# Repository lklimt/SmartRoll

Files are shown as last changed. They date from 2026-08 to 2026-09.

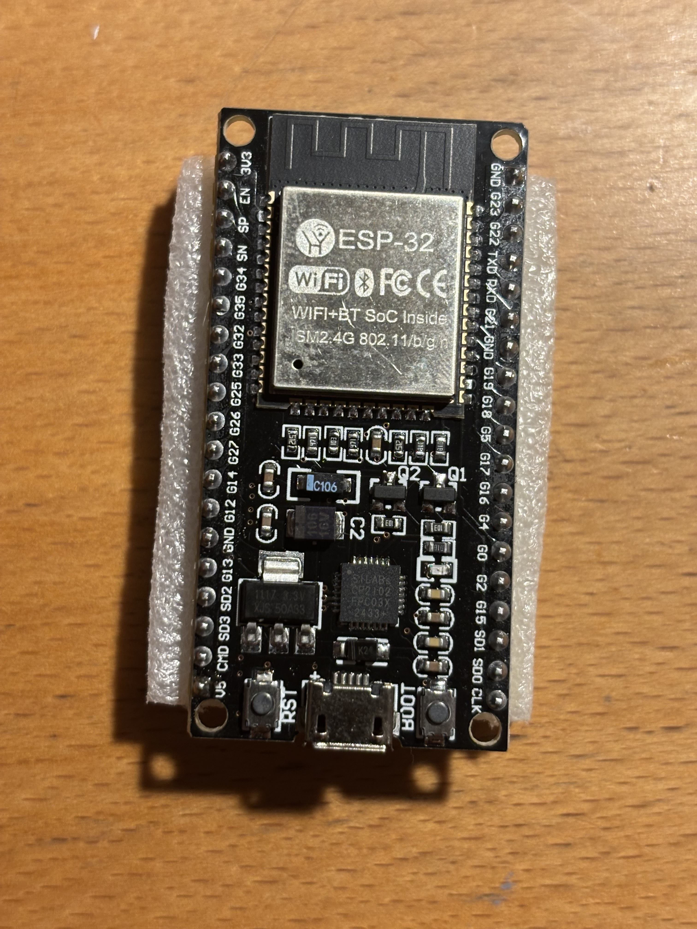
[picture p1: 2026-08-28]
images/components/ESP32-DevKit-38pin.jpeg

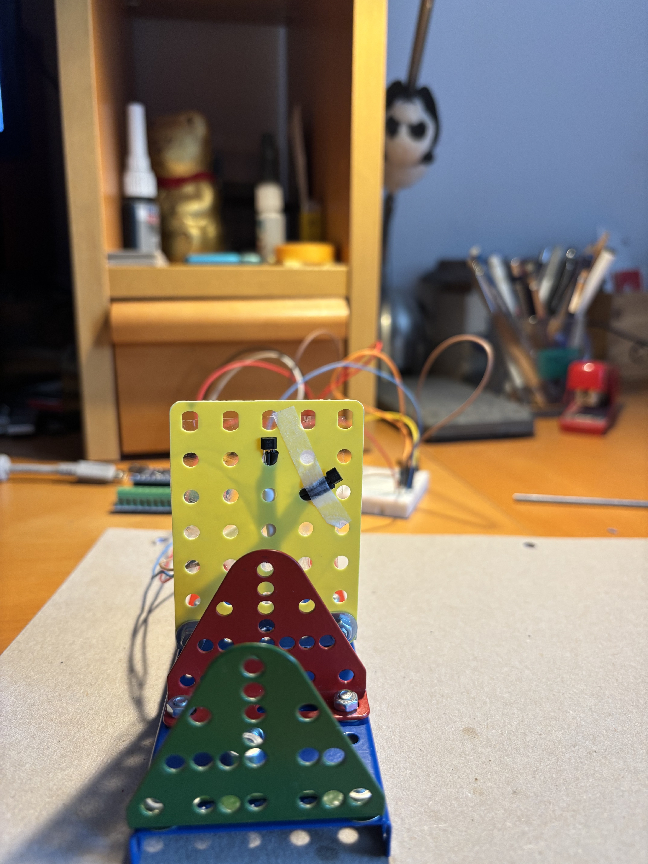
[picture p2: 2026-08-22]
tests/hall_sensor_test/evidence/hall-45stupnu.jpeg

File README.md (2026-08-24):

# SmartRoll

Automated control system for external roller blinds with **ERTE ET 45E tubular motors**.

SmartRoll combines the previously developed ControlRoll RF control with Hall-based direction/position sensing and additional environmental sensors in **one Wemos D1 mini / ESP8266 controller**.

## Project documentation

- [Technical Specification](SPECIFICATION.md)
- [System Architecture and D1 feasibility](docs/09_system_architecture.md)
- [Mechanical Design](docs/02_mechanical_design.md)
- [Hall Sensor Specification](docs/03_hall_sensor.md)
- [Electronics](docs/04_electronics.md)
- [Change Log](CHANGELOG.md)

## Target single-ESP architecture

One Wemos D1 mini / ESP8266 is planned to handle:

- Hall A + Hall B quadrature direction sensing
- relative roller position counting
- 433 MHz RF UP / STOP / DOWN control
- motion sensor
- temperature sensor
- light sensor
- Wi-Fi / Home Assistant communication

The Arduino Nano remains a **development/test platform only**.

## Initial GPIO allocation

| Function | Wemos pin | ESP GPIO |
|---|---|---:|
| Hall A | D1 | GPIO5 |
| Hall B | D2 | GPIO4 |
| Motion | D5 | GPIO14 |
| Temperature | D6 | GPIO12 |
| RF transmitter | D7 | GPIO13 |
| Light | A0 | ADC |

D3/GPIO0, D4/GPIO2 and D8/GPIO15 are reserved because they are ESP8266 boot-sensitive pins.

## Approved Hall arrangement

```text
2 magnets, 180° apart
Hall A + Hall B directly beside each other
5 mm successful test air gap

CW : 11 → 10 → 00 → 01 → 11
CCW: 11 → 01 → 00 → 10 → 11
```

The quadrature decoder and restart direction recovery have been experimentally validated on the Arduino Nano test fixture.

## Relationship to ControlRoll

The previous [ControlRoll](https://github.com/lklimt/ControlRoll) project used a Wemos D1 together with a separate Arduino Nano for RF transmission. SmartRoll is the next architecture: RF generation is moved into the ESP8266 so the production controller does not require the Arduino Nano.

The existing ControlRoll RF protocol and roller command codes are retained as the reference for the RF migration and must be verified before production firmware release.

## Repository structure

```text
SmartRoll/
├── README.md
├── SPECIFICATION.md
├── CHANGELOG.md
├── docs/
│   ├── 01_project_overview.md
│   ├── 02_mechanical_design.md
│   ├── 03_hall_sensor.md
│   ├── 04_electronics.md
│   ├── 05_firmware.md
│   ├── 06_home_assistant.md
│   ├── 07_testing.md
│   ├── 08_manufacturing.md
│   └── 09_system_architecture.md
├── mechanical/
│   ├── freecad/
│   │   ├── macros/
│   │   ├── models/
│   │   └── references/
│   ├── stl/
│   └── drawings/
├── electronics/
│   ├── schematics/
│   └── pcb/
├── firmware/
├── measurements/
├── tests/
└── images/
```

The technical specification is the source of truth for approved project parameters. Experimental results are retained as evidence but do not override the approved specification.

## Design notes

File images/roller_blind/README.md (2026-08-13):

# Roller Blind – General Photos

Photographs documenting the complete external roller-blind installation and its mechanical surroundings.

Use this directory for:
- overall installation views,
- motor-side views,
- wall/cassette relationship,
- available clearance,
- general orientation references.

File naming convention:
`NN_description.ext`

Example: `01_overall_motor_side.jpg`

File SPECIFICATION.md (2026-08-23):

# SmartRoll – Technical Specification

**Project:** SmartRoll  
**Repository:** `lklimt/SmartRoll`  
**Status:** Work in Progress  
**Current mechanical revision:** SR-MEC-001 Rev.F

## 1. Purpose

SmartRoll is an automated control system project for **external roller blinds equipped with ERTE ET 45E tubular motors**.

The project includes the mechanical carrier, magnetic sensing, electronics, firmware, Home Assistant integration, testing and manufacturing documentation.

This document is the technical source of truth for the project.

## 2. Specification Rules

- **CONFIRMED** – directly measured or explicitly confirmed.
- **DECIDED** – explicitly approved design decision.
- **ASSUMED** – temporary assumption; not a final manufacturing dimension.
- **OPEN** – information still requiring measurement or decision.
- **SUPERSEDED** – previous value/design replaced by a newer result.

Unknown dimensions shall be marked `OPEN`, never invented.

FreeCAD macros are implementation tools, not the source of design requirements. A macro must derive fixed dimensions and geometry from this specification and must not silently introduce final values for `OPEN` parameters.

Every substantial mechanical change receives a new revision. Historical revisions remain historical.

# 3. Mechanical System

## 3.1 Roller-blind application

- Application: **external roller blinds**.
- Motor: **ERTE ET 45E tubular motor**.

**Status: CONFIRMED**

## 3.2 Roller-blind shaft

The roller blind uses an octagonal shaft.

| Parameter | Value | Status |
|---|---:|---|
| Shaft type | Octagonal | CONFIRMED |
| Across flats | 16.70 mm | CONFIRMED |
| Surface containing slat feature | 5 + 6.7 + 5 mm | CONFIRMED |
| Carrier clamping zone width | 6 mm | DECIDED |

The 16.70 mm value is the relevant distance across opposing flats. The face containing the slat feature is the primary mechanical reference.

The exact global CAD coordinate convention remains **OPEN** and shall be fixed before the production macro is finalized.

## 3.3 Available space

| Condition | Available space | Status |
|---|---:|---|
| Blind unrolled | approx. 35 mm from wall | CONFIRMED |
| Blind wound | approx. 30 mm effective space | CONFIRMED |

The approximately 30 mm wound condition is the limiting clearance condition unless a later measurement establishes a smaller value.

## 3.4 Stationary and rotating areas

The right-hand side contains a stationary black mounting part including the motor programming button. The rotating part begins approximately **24 mm from the right-hand side**.

The magnetic carrier must not:

- contact the stationary mounting part,
- obstruct the programming button,
- prevent operation or programming of the ERTE ET 45E motor,
- enter the stationary portion of the mechanism.

**Status: CONFIRMED / APPROXIMATE where noted; DECIDED as design constraint.**

# 4. Magnetic Carrier – SR-MEC-001

The carrier is a **two-piece component** clamped around the octagonal shaft. The two halves are installed independently and mechanically joined.

The carrier consists of two functional zones:

1. **Shaft clamping zone** – positively locked to the octagonal shaft.
2. **Magnetic rotating zone** – carries the magnets and provides circular clearance around the stationary mechanism.

The two zones must not be confused: the shaft-clamping geometry follows the octagonal shaft, while the magnetic section uses circular rotating clearance.

**Status: DECIDED**

## 4.1 Shaft clamping

- Octagonal internal geometry matching the shaft.
- Shaft AF: **16.70 mm**.
- Clamping section width: **6 mm**.
- Rotation shall be transmitted positively and shall not rely on friction alone.
- Slat clearance shall be provided on the correct shaft face.

## 4.2 Slat clearance

The slat clearance is rotated **90° relative to the carrier split / M3 joining arrangement**.

The clearance shall be large enough for the actual shaft feature while removing as little carrier material as practical.

Exact depth and detailed shape remain **OPEN** until measured geometry is entered.

## 4.3 M3 clamping

The two carrier halves use **two M3 connections**.

Requirements:

- closed screw bosses,
- accessible M3 screw heads,
- M3 nut pockets with anti-rotation retention,
- hardware outside the rotating clearance,
- sufficient material around the bosses.

The two halves shall clamp the shaft securely without obstructing the magnetic rotation.

# 5. Approved Magnet Arrangement

| Parameter | Value | Status |
|---|---:|---|
| Number of magnets | 2 | DECIDED |
| Angular separation | 180° | DECIDED |
| Magnet orientation | Radial | DECIDED |
| Magnet polarization | Same in tested arrangement | CONFIRMED |
| Nominal magnet size | 4 × 2 mm | DECIDED |

The magnets are positioned opposite each other and inserted radially from the outside of the carrier into secure pockets.

The final pocket depth and exact retention method remain **OPEN** until production verification.

# 6. Approved Hall Sensor Arrangement

The approved Hall arrangement is:

- **2 Hall sensors**, Hall A and Hall B,
- Hall A and Hall B mounted **directly beside each other**,
- no intentional large angular separation between Hall A and Hall B,
- nominal tested air gap: **5 mm**.

This close A/B arrangement is essential to the verified quadrature signal and avoids an unwanted magnetic dead zone between the sensors.

A **10 mm** air gap was experimentally found unreliable. **5 mm** was reliable, including rapid manual rotation faster than the expected roller-blind motor speed.

**Status: APPROVED TEST CONFIGURATION.**

The exact production Hall mounting dimensions and final air gap remain subject to mechanical verification.

# 7. Approved Hall Quadrature Signal

With Hall A and Hall B directly beside each other, the experimentally verified state sequences are:

### Clockwise rotation – CW

```text
11 → 10 → 00 → 01 → 11
```

### Counter-clockwise rotation – CCW

```text
11 → 01 → 00 → 10 → 11
```

All four states occur:

```text
00
01
10
11
```

The two physical directions therefore produce opposite state ordering and can be distinguished unambiguously.

# 8. Approved Direction Decoder

SmartRoll shall use a **2-bit quadrature state-transition decoder** based on the complete previous-state → new-state transition.

## 8.1 CW transitions

```text
11 → 10
10 → 00
00 → 01
01 → 11
```

Each is one valid CW movement increment.

## 8.2 CCW transitions

```text
11 → 01
01 → 00
00 → 10
10 → 11
```

Each is one valid CCW movement increment.

## 8.3 Invalid transitions

Any transition not listed above is **INVALID**.

An invalid transition shall:

- increment a diagnostic invalid-transition counter,
- not count as normal movement,
- not by itself reverse the detected direction.

The decoder must not determine direction from either Hall signal individually.

## 8.4 Physical direction vs blind movement

`CW` and `CCW` describe physical rotation only.

The final system shall map physical direction to:

- **WIND** – movement toward the rolled-up position.
- **UNWIND** – movement toward the extended position.

This mapping shall be configurable during installation/calibration and shall not be hard-coded from assumed sensor orientation.

# 9. Restart and Power-Failure Behavior

The controller must reacquire direction after restart or power failure without requiring the previous direction to survive in RAM.

Startup procedure:

1. Read the current Hall A/B state.
2. Store it as `previousState`.
3. Set direction to `UNKNOWN`.
4. Wait for the next Hall state change.
5. Decode the valid transition.
6. Set direction to CW or CCW.
7. Continue relative movement counting.

Example:

```text
Restart
  ↓
Read A/B = 11
  ↓
Direction = UNKNOWN
  ↓
11 → 10
  ↓
Direction = CW
```

The opposite valid transition similarly establishes CCW.

The controller shall not infer direction from the motor command alone and shall not assume that the blind is stationary at startup.

**Status: DECIDED and experimentally verified on Arduino Nano.**

# 10. Absolute Position After Power Failure

Exact absolute blind position recovery immediately after a power failure is **not required**.

The ERTE ET 45E motor has programmed upper and lower travel limits. Hall sensing is therefore used for relative rotation and movement counting.

A power failure during movement may temporarily leave the software position offset from the physical position. This is acceptable.

After complete travel to a known upper or lower motor endpoint, SmartRoll shall resynchronize its software position to that known endpoint.

No additional absolute-position sensor is required for this recovery concept.

**Status: DECIDED.**

# 11. Relative Position Counting – OPEN

Valid quadrature transitions provide signed relative movement counts.

The system shall distinguish between:

- raw Hall state changes,
- valid quadrature transitions,
- signed shaft rotation count,
- calibrated blind position.

The following values still require measurement and shall not be guessed:

- valid transitions per shaft revolution,
- shaft revolutions per full blind travel,
- conversion between Hall count and blind position.

# 12. Verification Completed

The approved Hall concept has been experimentally verified on the Merkur-based development fixture using an Arduino Nano.

Completed tests:

1. Two magnets 180° apart.
2. Hall A/B sensors directly beside each other.
3. CW and CCW state-sequence verification.
4. Five rotations CW and five rotations CCW.
5. Direction changes during operation.
6. Rapid manual rotation faster than expected roller-blind motor speed.
7. 5 mm air-gap reliability test – reliable.
8. 10 mm air-gap test – unreliable.
9. Reset while operating CW.
10. Reset while operating CCW.
11. Correct direction reacquisition after reset.
12. No invalid transitions in the recorded normal-operation tests.

The quadrature direction algorithm is therefore **experimentally validated on the Arduino Nano test platform**.

Evidence is stored in:

```text
/tests/hall_sensor_test/evidence/
```

Detailed measurement history is stored in:

```text
/tests/hall_sensor_test/measurement_log.md
```

# 13. Test Platform vs Production Platform

The Arduino Nano / ATmega328P is **test hardware only**.

The final SmartRoll control unit will use an **ESP microcontroller**.

Therefore:

- Arduino pin assignments are not production assignments.
- Arduino-specific timing/interrupt implementation is not a production requirement.
- The validated quadrature transition behavior is the functional requirement.
- Final ESP firmware shall implement equivalent behavior using ESP-compatible GPIO handling.

# 14. Production Electrical Parameters – OPEN

The following require final component selection and verification:

- Hall sensor part number,
- final ESP model,
- ESP GPIO assignments,
- Hall supply voltage,
- Hall output type/polarity,
- pull-up arrangement,
- input protection,
- filtering/debounce if required,
- maximum expected transition frequency.

# 15. Mechanical Verification Requirements

Before a carrier revision is considered production-ready, verify:

1. correct 16.70 mm shaft engagement,
2. correct slat clearance,
3. correct orientation of the carrier halves,
4. secure M3 clamping,
5. accessible M3 screw heads,
6. correct nut retention,
7. secure magnet retention,
8. magnets remain 180° apart,
9. Hall A/B remain directly beside each other,
10. production air gap is within the validated magnetic operating range,
11. no intrusion into circular rotating clearance,
12. no interference with the stationary mounting part,
13. programming button remains accessible,
14. sufficient clearance in the approximately 30 mm wound condition,
15. secure torque transmission from shaft to carrier.

A CAD model alone does not constitute mechanical verification.

# 16. Parameters That Must NOT Be Guessed

The following shall remain `OPEN` unless explicitly measured or decided:

- exact stationary-holder diameter,
- exact distance between stationary holder and wall,
- exact programming-button geometry,
- exact slat-feature geometry,
- exact depth and width of slat clearance,
- final carrier outer diameter,
- final magnetic-section dimensions,
- final magnet-pocket geometry,
- final M3 boss dimensions,
- final printing tolerances,
- final material and print orientation,
- final Hall mounting dimensions,
- final production air gap,
- position calibration constants.

# 17. FreeCAD Macro Requirements

Production macros shall:

- contain clearly named parameters,
- separate confirmed/decided dimensions from `OPEN` dimensions,
- generate both carrier halves,
- preserve the 16.70 mm octagonal shaft geometry,
- preserve the 6 mm clamping-zone width,
- include the slat clearance in the correct orientation,
- provide circular rotating clearance in the magnetic section,
- place two radial magnet pockets 180° apart,
- preserve the approved Hall A/B installation geometry,
- provide two functional M3 joining bosses,
- provide complete M3 screw-head seats,
- provide anti-rotation nut pockets,
- keep M3 hardware outside the rotating clearance,
- keep the programming button accessible,
- expose `OPEN` dimensions at the top of the macro,
- never silently replace confirmed dimensions with approximations.

# 18. Superseded Hall Experiments

Previous experiments using Hall sensors separated by approximately **30°, 45° or 90°** are now **SUPERSEDED**.

They are retained only as historical evidence. They shall **not** be used as:

- production mechanical references,
- firmware references,
- direction-algorithm references,
- geometry references for the final Hall installation.

In particular, the former 30° arrangement and its associated state machine are obsolete.

The approved reference is exclusively:

```text
2 magnets, 180° apart
Hall A + Hall B directly beside each other
5 mm successful test air gap

CW : 11 → 10 → 00 → 01 → 11
CCW: 11 → 01 → 00 → 10 → 11
```

# 19. Current Approved Hall Status

### APPROVED

- external roller blinds with ERTE ET 45E motors,
- 2 magnets,
- magnets 180° apart,
- same magnet polarization in tested arrangement,
- radial magnet orientation,
- 2 Hall sensors,
- Hall A/B directly beside each other,
- successful 5 mm test air gap,
- 2-bit quadrature decoding,
- complete-state transition direction detection,
- invalid-transition handling,
- restart direction reacquisition,
- relative movement counting concept,
- no requirement for exact absolute position immediately after power failure,
- endpoint resynchronization using motor limits,
- Arduino Nano as test platform,
- ESP as final controller platform.

### OPEN

- final Hall sensor selection,
- final ESP model and GPIO assignment,
- production Hall mounting dimensions,
- production air gap,
- electrical interface details,
- transitions per revolution calibration,
- blind-position calibration,
- final mechanical carrier verification.

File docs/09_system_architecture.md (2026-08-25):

# SmartRoll – System Architecture

**Status:** APPROVED ARCHITECTURE BASELINE / implementation OPEN

## 1. Objective

SmartRoll combines the functions previously developed in the separate `ControlRoll` project with the new SmartRoll sensing and position functions.

The preferred target is **one ESP32 development/controller board per roller blind**.

The controller shall provide:

- RF control of the ERTE ET 45E roller-blind motor,
- Hall A/B rotation and direction sensing,
- relative position counting,
- temperature sensing,
- light sensing,
- Wi-Fi communication,
- Home Assistant integration.

**PIR motion detection is not part of SmartRoll v1.** Hall A/B is the authoritative sensor for physical roller movement. A PIR, if required in the future, would detect people/presence in the room and would be an independent automation input, not a roller-motion sensor.

The previous ControlRoll architecture used a Wemos D1 communicating with a separate Arduino Nano which generated the RF signal. SmartRoll removes that Arduino from the production system. The ESP shall generate the RF output directly.

The existing Wemos D1 / ESP8266 remains a useful development and fallback platform.

## 2. Controller Decision

**ESP32 is now the preferred final controller platform.**

Reason:

- substantially more GPIO resources,
- greater processing and memory headroom,
- hardware peripherals suitable for timing-sensitive work,
- sufficient resources for Hall decoding, RF, Wi-Fi and all planned v1 sensors simultaneously.

The project shall nevertheless verify RF + Hall + Wi-Fi concurrency before the controller platform is considered production-frozen.

## 3. Feasibility Result

**Result: FEASIBLE on one ESP32.**

The planned v1 functions require only a small subset of normal ESP32 GPIO resources.

The ESP32 has sufficient GPIO and peripheral resources to avoid the GPIO compromises that were present on the ESP8266 design.

## 4. Proposed ESP32 GPIO Allocation

Initial development allocation:

| Function | ESP32 GPIO | Direction | Status |
|---|---:|---|---|
| Hall A | GPIO32 | input | PROPOSED |
| Hall B | GPIO33 | input | PROPOSED |
| BH1750 SDA | GPIO21 | I2C | PROPOSED |
| BH1750 SCL | GPIO22 | I2C | PROPOSED |
| RF transmitter | GPIO25 | output | PROPOSED |
| DS18B20 | GPIO26 | 1-Wire | PROPOSED |
| Light / ADC spare | GPIO34 | input-only ADC | PROPOSED |

PIR is deliberately not assigned a GPIO in v1.

## 5. Hall Sensors

Hall A and Hall B use the experimentally validated quadrature arrangement.

Approved mechanical arrangement:

- two magnets 180° apart,
- Hall A and Hall B directly beside each other,
- successful tested air gap 5 mm.

Approved state sequences:

```text
CW : 11 → 10 → 00 → 01 → 11
CCW: 11 → 01 → 00 → 10 → 11
```

The ESP firmware shall implement the same complete 2-bit state-transition decoder validated on the Arduino Nano.

**Hall A/B is the authoritative source of roller shaft movement and direction.** PIR must never be used to determine whether the roller is moving.

Hall inputs must be electrically compatible with the ESP32 3.3 V GPIOs. Pull-up strategy shall be finalized with the selected Hall sensor.

## 6. RF Control – FROZEN PROTOCOL

The existing ControlRoll project contains the reverse-engineered and validated ERTE 433 MHz RF control protocol.

This protocol is now **FROZEN** as a SmartRoll reference.

The following shall not be changed during migration:

- ERTE command data,
- roller addressing,
- UP / STOP / DOWN semantics,
- TRIBIT encoding,
- validated RF timing parameters.

The implementation reference is documented in:

`docs/11_controlroll_rf_protocol.md`

The `RF433send` library explicitly supports AVR, ESP8266 and ESP32. SmartRoll shall first reproduce the existing protocol directly on ESP32 using the same library and parameters.

Only after successful physical verification may a hardware-timed alternative be considered.

## 7. RF + Hall Timing Requirement

The most important SmartRoll RF test is simultaneous operation:

```text
Hall A/B rotation
        +
433 MHz RF transmission
        +
Wi-Fi active
```

Acceptance requires:

- no missed Hall transitions,
- no false direction changes,
- no unexpected invalid transitions,
- no RF command corruption,
- no watchdog reset.

The existing RF library uses microsecond timing and therefore the concurrency test is mandatory.

## 8. Temperature Sensor

A DS18B20 1-Wire sensor is initially allocated to GPIO26.

The sensor pull-up and exact wiring shall be verified on the ESP32 prototype.

Temperature measurement shall be scheduled without blocking time-critical Hall processing.

## 9. Light Sensor

BH1750 is initially allocated to I2C:

```text
SDA = GPIO21
SCL = GPIO22
```

The final sensor implementation remains subject to physical testing and calibration.

If an analog light sensor is considered later, an appropriate ADC pin shall be selected instead.

## 10. Power Architecture – 230 VAC to Isolated 5 V DC

The production concept shall use a **compact isolated AC/DC module**, not a large DIN-rail supply.

Preferred candidate:

**Hi-Link HLK-PM01 – 100–240 VAC input → 5 V DC / 0.6 A / 3 W, isolated.**

The module is approximately 34 × 20 × 15 mm and is intended for embedded installation. The selected supplier documentation specifies an isolated output and recommends appropriate input protection such as fuse and varistor. citeturn0search0turn0search24

The proposed architecture is:

```text
230 VAC
   │
   ├── mains input protection
   │
   ▼
┌─────────────────┐
│    HLK-PM01     │
│ 230 VAC → 5 VDC │
│     0.6 A       │
│    isolated     │
└────────┬────────┘
         │ 5 V DC
         ▼
       ESP32
         │
    ┌────┼───────────────┐
    │    │       │       │
   Hall  RF    BH1750  DS18B20
```

### Power-supply status

HLK-PM01 is **PREFERRED CANDIDATE, NOT YET PRODUCTION-FROZEN**.

The 0.6 A continuous rating must be verified under representative worst-case operation:

- ESP32 Wi-Fi active,
- RF transmission,
- Hall processing,
- BH1750 active,
- DS18B20 conversion.

If the 5 V rail becomes unstable or the ESP32 reports brownouts, a higher-current compact isolated AC/DC module shall be selected.

The former 5 V / 3 A DIN-rail supply is therefore no longer the baseline purchase item, but remains a possible laboratory fallback.

### Mains safety

The AC/DC module is directly connected to hazardous mains voltage. The final SmartRoll PCB/enclosure must maintain the required separation between mains and SELV circuitry and provide suitable protection, insulation, terminals and strain relief.

The exact fuse, surge protection, creepage/clearance and enclosure arrangement remain OPEN until the final PCB and mechanical design. Mains wiring shall not be performed on the current low-voltage prototype board.

## 11. Wi-Fi and Home Assistant

The ESP32 provides Wi-Fi directly.

The production controller shall expose at least:

- roller state,
- requested movement,
- physical rotation direction,
- relative position/count,
- temperature,
- light level,
- Hall invalid-transition diagnostics,
- communication/availability state.

The exact MQTT / ESPHome / native API architecture remains OPEN and will be selected after the firmware architecture is frozen.

## 12. Firmware Architecture

```text
SmartRoll firmware
│
├── hall
│   ├── Hall A/B input
│   └── quadrature decoder
│
├── roller
│   ├── direction
│   ├── relative position
│   ├── movement state
│   └── endpoint synchronization
│
├── rf
│   ├── UP
│   ├── STOP
│   └── DOWN
│
├── sensors
│   ├── temperature
│   └── light
│
├── network
│   └── Wi-Fi
│
└── integration
    └── Home Assistant
```

No module shall contain long blocking delays that can prevent Hall events from being processed.

## 13. PIR / Presence – FUTURE ONLY

PIR is intentionally excluded from SmartRoll v1.

If later added, its purpose would be **human movement/presence detection in the room**, for example to support comfort or energy-saving automation.

It would not replace or supplement the Hall-based roller movement measurement.

Any future PIR implementation shall be documented as an independent automation input.

## 14. Power and Logic Levels

The ESP32 uses 3.3 V logic.

The HLK-PM01 supplies 5 V to the ESP32 development board/prototype. The ESP32's onboard regulator then provides the required 3.3 V rail for the ESP32 and compatible sensors.

Every external sensor and RF module shall be checked for:

- supply voltage,
- GPIO high/low levels,
- maximum ESP32 GPIO voltage,
- pull-ups/pull-downs,
- startup state.

No 5 V signal shall be connected directly to an ESP32 GPIO without verification of compatibility.

## 15. Development vs Production Hardware

### Development

- Arduino Nano: validated Hall algorithm test platform.
- Wemos D1 / ESP8266: existing ControlRoll and fallback development platform.
- ESP32: preferred SmartRoll integration/test platform.
- Merkur fixture: Hall mechanical test platform.
- Existing ControlRoll hardware: RF protocol reference.

### Production target

- one ESP32 controller,
- two Hall sensors,
- two magnets,
- RF transmitter,
- temperature sensor,
- light sensor,
- compact isolated 230 VAC → 5 V DC power module.

The Arduino Nano is not part of the production controller.

## 16. Feasibility Conclusion

The one-controller architecture is accepted as the project direction.

ESP32 is the preferred controller because it gives sufficient GPIO and processing headroom without forcing sensors onto boot-sensitive pins.

The compact isolated HLK-PM01 power architecture is now the preferred power concept because it fits the expected low power demand and the physical constraints of an embedded SmartRoll controller better than a 15 W DIN-rail supply.

The remaining feasibility risks are:

1. direct ESP32 RF timing compatibility,
2. RF module electrical level compatibility,
3. Hall interrupt reliability while RF is transmitting,
4. exact sensor component selection and electrical interface,
5. HLK-PM01 0.6 A power margin under worst-case load,
6. final mains protection and PCB/enclosure safety.

These shall be verified before the first production firmware release.

## 17. Open Items

- final ESP32 board variant,
- exact Hall sensor production part number,
- exact temperature sensor wiring,
- exact light sensor implementation,
- RF transmitter module and electrical interface,
- whether an RF receiver is ultimately required,
- RF + Hall concurrency result,
- final Home Assistant communication method,
- final PCB/electrical protection,
- HLK-PM01 load test result,
- final mains protection and enclosure arrangement,
- whether a future PIR/presence feature is desired.

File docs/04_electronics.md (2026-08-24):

# SmartRoll – Electronics

**Status:** Architecture approved; component-level details OPEN

SmartRoll shall use **one Wemos D1 mini / ESP8266** as the production controller for one external roller blind with an ERTE ET 45E motor.

## 1. Functional Hardware

The controller is intended to combine:

- two Hall sensors for quadrature rotation/direction detection,
- two magnets on the rotating carrier,
- 433 MHz RF transmitter for UP/STOP/DOWN control,
- motion sensor,
- temperature sensor,
- light sensor,
- Wi-Fi / Home Assistant communication.

The Arduino Nano used during Hall testing is development hardware only and is not part of the production architecture.

## 2. Initial GPIO Allocation

| Function | Wemos | ESP GPIO | Status |
|---|---|---:|---|
| Hall A | D1 | GPIO5 | DECIDED |
| Hall B | D2 | GPIO4 | DECIDED |
| Motion | D5 | GPIO14 | DECIDED |
| Temperature | D6 | GPIO12 | DECIDED |
| RF transmitter | D7 | GPIO13 | DECIDED |
| Light sensor | A0 | ADC | DECIDED |
| Spare | D0 | GPIO16 | RESERVED |
| Boot-sensitive | D3 | GPIO0 | RESERVED |
| Boot-sensitive / serial TX | D4 | GPIO2 | RESERVED |
| Boot-sensitive | D8 | GPIO15 | RESERVED |

ESP8266 boot mode depends on GPIO0, GPIO2 and GPIO15; therefore SmartRoll shall not assign ordinary sensor functions to these pins without an explicit electrical boot analysis.

## 3. Hall Interface

Hall A/B use the approved SmartRoll quadrature arrangement. The ESP firmware must implement the validated state-transition decoder.

```text
CW : 11 → 10 → 00 → 01 → 11
CCW: 11 → 01 → 00 → 10 → 11
```

Hall input electrical compatibility with 3.3 V ESP8266 GPIOs must be confirmed against the final Hall sensor.

## 4. RF Interface

The former ControlRoll system used an Arduino Nano to drive the 433 MHz transmitter. SmartRoll will move the RF generation into the ESP8266.

Initial RF output assignment:

```text
Wemos D7 / GPIO13 → RF transmitter DATA
```

The exact RF transmitter module and its 3.3 V/5 V data compatibility remain OPEN.

The existing ControlRoll RF protocol and per-roller codes are the starting reference and must be migrated only after verification.

## 5. Sensors

### Motion

Initial allocation: D5 / GPIO14.

Exact sensor and active level: OPEN.

### Temperature

Initial allocation: D6 / GPIO12.

A 1-Wire sensor is the current architectural assumption. Exact component and pull-up: OPEN.

### Light

Initial allocation: A0.

The final sensor/divider must be designed so the Wemos D1 mini ADC input remains within its specified range.

## 6. Timing Requirement

The Hall decoder must remain responsive during RF transmission.

Hall processing shall be interrupt/event driven or otherwise guaranteed not to miss valid transitions.

The ESP RF implementation shall not use long blocking operations that can prevent Hall processing, Wi-Fi servicing or watchdog servicing.

This interaction is a mandatory integration test before production firmware approval.

## 7. Power and Logic Levels

All external interfaces shall be checked for:

- supply voltage,
- logic-high and logic-low levels,
- maximum GPIO voltage,
- pull-up/pull-down requirements,
- startup state,
- current consumption.

The old ControlRoll RF hardware used 5 V supply on the Arduino side. Direct connection to ESP8266 GPIO must therefore not be assumed safe until the RF module data input/output levels are verified.

## 8. Detailed Component Selection – OPEN

- Hall sensor part number,
- RF transmitter module,
- RF receiver requirement,
- motion sensor,
- temperature sensor,
- light sensor,
- power supply,
- protection and filtering,
- final PCB implementation.

See [`docs/09_system_architecture.md`](09_system_architecture.md) for the complete single-ESP architecture and GPIO feasibility analysis.

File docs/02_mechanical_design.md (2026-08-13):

# SmartRoll – Mechanical Design

## 1. Purpose

This document consolidates the physical measurements, approved design decisions and lessons learned from the FreeCAD development history of the SmartRoll magnetic carrier for external roller blinds with ERTE ET 45E motors.

The current design target is **SR-MEC-001**. Historical CAD revisions are evidence of development only; they are not automatically the current specification.

## 2. Physical reference geometry

### Shaft

- Octagonal roller-blind shaft.
- Confirmed across flats: **16.70 mm**.
- The face containing the slat feature is geometrically `5.0 + 6.7 + 5.0 mm`.
- The previously used **7.00 mm** side dimension is obsolete.

The repository also contains the note `Hridel - 8x 20 mm`. This should be interpreted as a nominal/profile description from the measurement note and must not replace the confirmed **16.70 mm across-flats** dimension.

### Installation envelope

- Cabinet depth: **160 mm**.
- Cabinet height: **160 mm**.
- Wound blind distance from wall: approximately **30 mm**.
- Available space when unwound: approximately **35 mm**.
- The wound condition is the limiting mechanical condition.
- The stationary black motor-holder and programming button are on the right side.
- The rotating section begins approximately **24 mm from the right-hand side**.

## 3. Approved carrier architecture

The carrier is divided into **two separate halves**.

This is an explicit design decision. The reason is installation: a complete ABS ring should not have to be elastically opened enough to pass over the shaft.

Installation is therefore:

1. place one half on the shaft;
2. place the second half on the opposite side;
3. engage the octagonal profiles;
4. align the slat clearance;
5. insert two M3 screws;
6. retain the M3 nuts in anti-rotation pockets;
7. tighten the carrier around the shaft.

## 4. Functional zones

The carrier has two different internal geometries.

### Zone A – shaft clamping

- Axial width: **6.00 mm**.
- Internal profile: octagonal.
- Reference shaft: **16.70 mm AF**.
- Function: positive torque transmission between shaft and carrier.

### Zone B – magnetic collar

- Axial width: **5.00 mm**.
- Total carrier axial width: **11.00 mm**.
- Internal profile: **circular**, not octagonal.
- Function: rotate freely around the stationary motor-holder.

This distinction is critical. Several historical CAD revisions explicitly document the correction from an octagonal magnetic bore to a circular bore.

## 5. Slat feature

The shaft has a slat feature on one octagonal face.

The carrier must provide clearance for this feature while retaining as much clamping material as possible.

The slat clearance is positioned **90° relative to the carrier joining arrangement**. This prevents the slat feature from being placed at the carrier split.

Exact clearance shape and depth remain OPEN until the physical feature is fully dimensioned.

## 6. Magnetic system

Two magnets are mounted in the rotating magnetic collar.

Approved properties:

- 2 magnets;
- 180° apart;
- radial orientation;
- insertion from the outside circumference;
- nominal magnet size: 4 × 2 mm.

The magnet pockets must not break through into the circular internal clearance. Final pocket dimensions remain dependent on the actual magnets and printing process.

## 7. M3 clamping system

Two M3 connections clamp the carrier halves together.

The design requirements established during the CAD iterations are:

- closed, mechanically complete M3 bosses;
- full support around the screw head;
- externally accessible screw head;
- anti-rotation hexagonal nut pocket;
- M3 hardware outside the circular rotating clearance;
- no interference with the stationary motor-holder.

A partially open boss or a boss containing only half of the screw-head radius is rejected.

## 8. Historical CAD development

The repository contains the following carrier development stages:

- `SR-MEC-001_RevA.FCMacro`
- `SR-MEC-001_RevB.FCMacro`
- `SR-MEC-001_RevC.FCMacro`
- `SR-MEC-001_RevD.FCMacro`
- `SR-MEC-001_RevE.FCStd`
- `SR-MEC-001_RevE1.FCMacro`
- `SR-MEC-001_RevE2.FCMacro`
- `SR-MEC-001_RevE3.FCMacro`
- `SR-MEC-001_RevE4.FCMacro`
- `SR-MEC-001_RevE5.FCMacro`

### Rev.A – initial complete concept

The first macro already contained several correct measured/design inputs:

- shaft AF 16.70 mm;
- 6 mm clamping length;
- 5 mm magnetic collar;
- 11 mm total width;
- two 4 × 2 mm magnets at 180°;
- M3 clamping concept.

However, it used a single split-ring concept and several provisional dimensions. It is historical only.

### Rev.E1

E1 explicitly established the important functional separation:

- 0–6 mm octagonal clamping bore;
- 6–11 mm circular Ø21 mm clearance;
- radial 4 × 2 mm magnets;
- magnets 180° apart;
- one continuous split.

The macro itself documents that the magnetic collar must not be octagonal because it has to rotate around the fixed holder.

### Rev.E2

E2 continued the single-slit architecture and explicitly intended the slit to allow the complete ring to be opened for shaft installation.

This concept was later rejected as impractical for tough ABS because sufficient elastic opening could not be guaranteed.

### Rev.E5

E5 is the latest macro currently present in the repository. It contains:

- 16.70 mm AF octagonal clamping section;
- 6 mm clamping width;
- 5 mm magnetic collar;
- Ø21 mm circular magnetic clearance;
- Ø26 mm outer diameter as a CAD reference;
- two closed M3 bosses;
- M3 head and nut pockets;
- radial magnet pockets at 90° / 270°;
- one continuous slot.

**Important:** E5 is the latest historical CAD implementation, but it is **not automatically the approved production revision** because the two-piece installation architecture and exact measured holder geometry still need to be reconciled.

## 9. Values that are CAD references, not physical measurements

The following values occur in the historical macros and must not be promoted to CONFIRMED without physical evidence:

- outer diameter Ø26 mm;
- magnetic clearance Ø21 mm;
- 0.20 mm shaft clearance;
- M3 hole Ø3.30 mm;
- M3 head recess values;
- nut pocket AF 5.50 mm;
- magnet pocket Ø4.20 mm × approximately 2.15 mm;
- slot width 0.80 mm.

They are retained as useful design-history references.

## 10. Design decisions superseding earlier concepts

### Superseded: single-piece ring opening

The carrier shall not depend on elastically opening a complete ABS ring for installation.

### Approved: two carrier halves

Both halves are placed separately around the shaft and clamped with two M3 connections.

### Superseded: octagonal magnetic bore

The magnetic collar must use circular clearance.

### Approved: radial magnets

Magnets are inserted from the outer circumference, not axially from the face.

### Superseded: 7 mm shaft side

The confirmed slat-side geometry is 5 + 6.7 + 5 mm.

## 11. Remaining critical measurements

Before a production FreeCAD macro is released, the following must be confirmed from the physical installation:

1. stationary-holder external diameter/profile;
2. exact right-side rotating/stationary boundary;
3. exact programming-button envelope;
4. exact slat feature depth and shape;
5. exact minimum wound-blind clearance at the carrier;
6. exact magnet dimensions of the selected parts;
7. exact Hall sensor mounting position;
8. final print-fit tolerances.

## 12. CAD rule for future revisions

Every future macro shall begin with a parameter block containing only:

- confirmed dimensions;
- explicit design decisions;
- clearly marked OPEN parameters.

A value copied from an older macro shall be labelled `REFERENCE` until independently confirmed.

No new FreeCAD macro is considered a production candidate merely because it renders successfully. It must first satisfy the mechanical specification and the installation/clearance checks.

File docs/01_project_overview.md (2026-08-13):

# SmartRoll – Project Overview

## Purpose

SmartRoll is an automated roller-blind control system combining mechanical drive components, rotational sensing, electronics, firmware and Home Assistant integration.

## Documentation principle

The repository is the long-term technical record of the project. The current approved `SPECIFICATION.md` is the source of truth for parameters.

## Development principle

Design iterations must preserve confirmed parameters unless an explicit change is agreed and recorded in `CHANGELOG.md`.

Unknown values remain `OPEN` until confirmed.

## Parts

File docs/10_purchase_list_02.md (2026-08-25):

# SmartRoll – Purchase List No. 2

**Purpose:** Complete the material needed to perform the remaining SmartRoll tests and, if successful, assemble one complete functional SmartRoll prototype.

**Date:** 2026-08-25

## 1. Controller decision

The project has frozen the existing ControlRoll ERTE RF protocol as the reference for SmartRoll migration.

The RF433send library explicitly supports **ESP32, ESP8266 and AVR**, so the RF protocol can be migrated without redesigning the protocol itself. The remaining question is timing reliability when RF, Hall quadrature and Wi-Fi operate simultaneously.

The purchase baseline is therefore **ESP32 as the preferred final controller**.

The existing Wemos D1 mini / ESP8266 remains useful as development/fallback hardware and does not need to be discarded.

## 2. What is already available

Purchase No. 1 has already covered the initial Hall experiment material:

- Hall sensors – already purchased
- magnets – already purchased
- resistors – already purchased
- capacitors – already purchased
- universal prototype PCB – already available
- Merkur test fixture – already available
- Arduino Nano – available as the current Hall test platform
- Wemos D1 mini – existing development hardware

These items are therefore not required for the new purchase, except where a spare is useful.

## 3. Main controller – PREFERRED PLATFORM

| Qty | Component | Preferred source | Reason |
|---:|---|---|---|
| 2 | ESP32-DevKitC 38pin, Micro USB | Drátek | 1× main development/test unit, 1× final/reserve unit |

Current candidate: **ESP32-DevKitC 38pin**. Drátek lists the board with ESP32 dual-core, 4 MB Flash, Wi-Fi/Bluetooth, 3.3 V logic and 5 V USB power. urlDrátek – ESP32-DevKitC 38pinhttps://dratek.cz/arduino-platforma/51547-esp32-devkitc-development-board-38pin.html

Two boards are recommended so that one can remain permanently available as the development/debug unit while the second becomes the basis of the complete SmartRoll prototype.

## 4. RF control

The final SmartRoll shall generate the already validated ControlRoll ERTE RF protocol directly from the ESP32.

| Qty | Component | Preferred source | Reason |
|---:|---|---|---|
| 2 | NiceRF STX882 433 MHz ASK transmitter | Drátek | 1× test, 1× final/reserve |
| 2 | 433 MHz antenna suitable for STX882 / 433.92 MHz | Drátek | RF test and final unit |
| 1 | NiceRF SRX882S receiver | Drátek | optional RF reception/diagnostic testing |

The existing ControlRoll RF protocol is frozen in:

`docs/11_controlroll_rf_protocol.md`

The protocol shall not be changed during migration. The first task is to reproduce the existing waveform on ESP32 and verify the ERTE motor responds identically.

The STX882 is the preferred transmitter candidate. The RF module electrical interface must still be verified before final PCB design.

## 5. Light sensor

| Qty | Component | Preferred source | Reason |
|---:|---|---|---|
| 1 | BH1750 light intensity sensor | Drátek | digital lux measurement via I2C |

BH1750 provides I2C light measurement. urlDrátek – BH1750 light sensorhttps://dratek.cz/arduino-platforma/902-mereni-intenzity-svetla-bh1750.html

## 6. Temperature sensor

| Qty | Component | Preferred source | Reason |
|---:|---|---|---|
| 2 | Waterproof DS18B20, 1 m cable | Drátek | 1× test, 1× final/reserve |

The DS18B20 is suitable for the planned 1-Wire temperature measurement. urlDrátek – waterproof DS18B20 1 mhttps://dratek.cz/arduino-platforma/848-vodeodolny-teplomer-pro-jednodeskove-pocitace-ds18b20-1m.html

## 7. PIR motion sensor – NOT PURCHASED

PIR is **removed from SmartRoll v1**.

Hall A/B already provide the required information about actual roller-shaft movement and direction. A PIR detects movement/presence of people in the room, which is a separate future automation function and is not required for roller control.

No PIR is therefore included in Purchase List No. 2.

If presence-based automation is later approved, PIR will be treated as an independent optional expansion and purchased separately.

## 8. Power supply – COMPACT 230 VAC SOLUTION

The previously considered 5 V / 3 A DIN-rail supply is **removed from the SmartRoll purchase baseline**.

The preferred solution is now a compact, isolated AC/DC module mounted inside the SmartRoll electronics enclosure:

| Qty | Component | Preferred source | Reason |
|---:|---|---|---|
| 1 | **Hi-Link HLK-PM01, 230 VAC → 5 V DC / 0.6 A / 3 W, isolated** | LaskaKit or Drátek | compact embedded supply for the complete prototype |

LaskaKit currently lists the HLK-PM01 as a 100–240 VAC input, isolated 5 V / 0.6 A module, approximately 34 × 20 × 15 mm. It is intended for embedded installation and includes overload/short-circuit protection. citeturn0search0turn0search24

Drátek also lists the HLK-PM01, 100–240 VAC input, 5 V / 600 mA, approximately 35 × 21 × 16 mm, for PCB mounting. citeturn0search2

**Status: PREFERRED CANDIDATE – NOT YET PRODUCTION-FROZEN.**

The 600 mA continuous rating must be verified experimentally with:

```text
ESP32 Wi-Fi active
+ RF transmitter
+ Hall A/B active
+ BH1750
+ DS18B20
```

If voltage stability or current reserve proves insufficient, a larger compact isolated AC/DC module will be selected. The first alternative should remain a 5 V module with greater current capacity rather than returning automatically to a large DIN supply.

### Required mains-side protection

Because this module is connected directly to 230 VAC, the final design shall include an appropriate mains input protection scheme. The HLK-PM01 documentation/recommendation calls for input protection such as a fuse and varistor. citeturn0search0turn0search24

The final mains section shall therefore be designed as:

```text
230 VAC
   │
   ├── fuse / overcurrent protection
   │
   ├── surge protection as required
   │
   ▼
HLK-PM01
   │
   │ isolated 5 V DC
   ▼
ESP32 + sensors + RF
```

The exact fuse, varistor, PCB creepage/clearance and enclosure arrangement remain open until the final PCB/mechanical design. Mains wiring is not part of the current low-voltage breadboard tests.

## 9. Prototyping accessories

| Qty | Component | Purpose |
|---:|---|---|
| 1 | Dupont jumper assortment M-M / M-F / F-F | prototyping |
| 1 | 2.54 mm pin-header assortment | PCB/module connections |
| 1 | 2-pin / 3-pin screw terminal assortment | permanent prototype connections |
| 1 | hookup-wire assortment | integrated prototype |
| 1 | heat-shrink assortment | insulation/strain relief |
| 1 | spare prototype PCB, if required | integrated prototype |

## 10. Recommended electrical spares

| Qty | Component | Purpose |
|---:|---|---|
| 5 | 100 nF ceramic capacitors | module decoupling |
| 5 | 10 µF electrolytic capacitors | local supply stabilization |
| 2 | 470 µF electrolytic capacitors | supply/RF transient reserve |
| 5 | 1 kΩ resistors | signal/general use |
| 5 | 4.7 kΩ resistors | I2C / 1-Wire pull-up/general use |
| 5 | 10 kΩ resistors | pull-up/pull-down/general use |

These values are support/spare values and are not yet frozen production values.

## 11. ESP32 prototype GPIO baseline

The exact final GPIO allocation will be chosen after the ESP32 RF and Hall concurrency test.

Recommended initial allocation:

| Function | ESP32 GPIO | Status |
|---|---:|---|
| Hall A | GPIO32 | PROPOSED |
| Hall B | GPIO33 | PROPOSED |
| BH1750 SDA | GPIO21 | PROPOSED |
| BH1750 SCL | GPIO22 | PROPOSED |
| RF transmitter | GPIO25 | PROPOSED |
| DS18B20 | GPIO26 | PROPOSED |
| Light / ADC spare | GPIO34 | PROPOSED INPUT ONLY |

These GPIOs are deliberately selected from ordinary ESP32 pins suitable for the intended functions. The final pinout shall be frozen only after the actual modules are tested.

## 12. Test sequence enabled by Purchase No. 2

### Test 1 – Hall

Already completed on Arduino Nano. The quadrature algorithm and reset behavior are experimentally validated.

### Test 2 – ESP32 Hall decoder

Port the approved Arduino quadrature decoder to ESP32.

Acceptance:

- CW correct,
- CCW correct,
- rapid rotation correct,
- reset recovery correct,
- no false direction changes.

### Test 3 – ESP32 RF

Port the frozen ControlRoll RF protocol without changing its data or timing reference.

Acceptance:

- UP works,
- STOP works,
- DOWN works,
- correct roller addressing is preserved,
- repeated transmissions are reliable.

### Test 4 – ESP32 + Hall + RF simultaneously

This is the key architecture test.

Acceptance:

- no lost Hall transitions,
- no false direction changes,
- no unexpected invalid transitions,
- no RF command corruption,
- no watchdog/reset.

### Test 5 – Sensors

Add:

- BH1750,
- DS18B20.

Verify simultaneous operation and Home Assistant/MQTT reporting.

### Test 6 – Power supply

After the low-voltage functions are proven, test the HLK-PM01 under representative worst-case load:

- ESP32 Wi-Fi active,
- RF transmission,
- Hall processing,
- BH1750 active,
- DS18B20 conversion,
- repeated RF commands.

Acceptance:

- stable 5 V rail,
- no ESP32 brownout/reset,
- no RF malfunction,
- no Hall event loss.

Only then may the HLK-PM01 be accepted for the integrated prototype.

### Test 7 – Complete SmartRoll prototype

Combine:

```text
230 VAC
+ HLK-PM01 5 V isolated supply
+ ESP32
+ Hall A/B
+ RF TX
+ BH1750
+ DS18B20
+ Wi-Fi/MQTT
```

Only after Tests 2–6 pass should the integrated controller be considered ready for mechanical installation.

## 13. Items intentionally NOT purchased yet

Do not buy these in quantity until the integrated tests are complete:

- custom SmartRoll PCB,
- final enclosure,
- production mains PCB,
- large quantity of Hall sensors/magnets,
- final RF antenna type/length,
- production connectors,
- final PCB protection components,
- additional level shifters unless testing proves one is required,
- PIR/presence sensor hardware.

## 14. Purchase priority

### MUST HAVE

1. **ESP32-DevKitC 38pin – 2 pcs**
2. **STX882 433 MHz transmitter – 2 pcs**
3. **433 MHz antennas – 2 pcs**
4. **BH1750 – 1 pc**
5. **DS18B20 waterproof – 2 pcs**
6. **HLK-PM01 230 VAC → 5 V / 0.6 A isolated – 1 pc**
7. jumper wires / headers / terminals
8. support capacitors/resistors

### RECOMMENDED

9. SRX882S receiver – 1 pc
10. spare prototype PCB
11. heat-shrink and hookup wire

## 15. Procurement rule

Preferred suppliers:

- **Drátek.cz**
- **LaskaKit.cz**

Availability and prices should be checked again immediately before ordering.

Any substitution with a different electrical interface shall be recorded in SmartRoll documentation before use.

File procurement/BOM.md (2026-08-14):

# SmartRoll – Bill of Materials (BOM)

## Purpose

Central purchasing list for the SmartRoll project.

**Preferred supplier:** Dratek.cz

The BOM separates confirmed project components from items that still depend on final electrical/mechanical verification. Product availability and prices are intentionally not frozen here; they must be checked at the time of purchase.

## 1. Mechanical carrier

| ID | Component | Specification | Qty | Status | Supplier |
|---|---|---|---:|---|---|
| MEC-001 | Printed magnetic carrier | SR-MEC-002 Rev.A Final Candidate; final material/print settings TBD | 1 set (2 halves) | DECIDED / CANDIDATE | 3D print |
| MEC-002 | Neodymium magnet | nominal 4 × 2 mm, 2 pcs, radial mounting, 180° apart | 2 | DECIDED; exact Dratek part OPEN | Dratek.cz |
| MEC-003 | Screw | M3, length to be confirmed from final carrier | 2 | OPEN | Dratek.cz |
| MEC-004 | Hex nut | M3, preferably suitable for anti-rotation pocket | 2 | DECIDED; exact type OPEN | Dratek.cz |

## 2. Hall sensing

| ID | Component | Specification | Qty | Status | Supplier |
|---|---|---|---:|---|---|
| SEN-001 | Hall sensor A | Digital Hall switch; exact part to be selected | 1 | OPEN | Dratek.cz |
| SEN-002 | Hall sensor B | Same type as Hall A | 1 | OPEN | Dratek.cz |
| SEN-003 | Sensor mounting hardware | According to final sensor holder design | TBD | OPEN | Dratek.cz / 3D print |

### Candidate Hall sensor at Dratek

Dratek currently lists **Hallův senzor 44E (A1344EUA-T)**, product code `1557994578`. It is a unipolar digital Hall sensor, specified for 4.5–24 V operation. This is a candidate only; it is **not yet approved as the final SmartRoll Hall sensor**, because the final magnetic polarity, sensor geometry and required quadrature behavior still need verification.

Reference: https://dratek.cz/arduino-platforma/7735-halluv-senzor-44e.html

## 3. Controller / electronics

| ID | Component | Specification | Qty | Status | Supplier |
|---|---|---|---:|---|---|
| ELE-001 | Microcontroller | Final controller architecture to be confirmed (Arduino/ESP platform) | 1 | OPEN | Dratek.cz |
| ELE-002 | Pull-up resistors | Value depends on Hall output and controller input | TBD | OPEN | Dratek.cz |
| ELE-003 | Decoupling capacitors | For Hall sensors and controller | TBD | OPEN | Dratek.cz |
| ELE-004 | Terminal/connectors | Final wiring design dependent | TBD | OPEN | Dratek.cz |
| ELE-005 | Power supply / DC-DC | Final input voltage and enclosure arrangement TBD | 1 | OPEN | Dratek.cz |

## 4. Wiring

| ID | Component | Specification | Qty | Status | Supplier |
|---|---|---|---:|---|---|
| CAB-001 | Sensor cable | Flexible multi-core cable, final length TBD | TBD | OPEN | Dratek.cz |
| CAB-002 | Wire/connectors | According to final controller installation | TBD | OPEN | Dratek.cz |

## 5. Current purchasing recommendation

Do **not** place the complete order yet.

The following items are reasonable candidates for early bench testing:

1. 2× Hall sensor 44E/A1344EUA-T.
2. M3 screws and M3 nuts for mechanical prototype testing.
3. Suitable small neodymium magnets for testing the Hall geometry.

The exact 4 × 2 mm magnet should be selected only after checking Dratek's current catalogue and the actual magnetic polarity required by the Hall sensor.

## 6. Important design rule

A component appearing in this BOM does not automatically mean that its exact commercial part number has been approved.

Status meanings:

- **CONFIRMED** – measured/verified project requirement.
- **DECIDED** – project design decision.
- **CANDIDATE** – possible component, not yet frozen.
- **OPEN** – selection still required.
- **SUPERSEDED** – historical item no longer valid.

No commercial component shall be frozen as the final part until its dimensions, electrical properties and mechanical compatibility with SmartRoll have been verified.

## 7. Supplier

Preferred supplier: **Dratek.cz**.

When purchasing, record the exact Dratek product name, product code, date of purchase and quantity in this BOM so that the build remains reproducible.

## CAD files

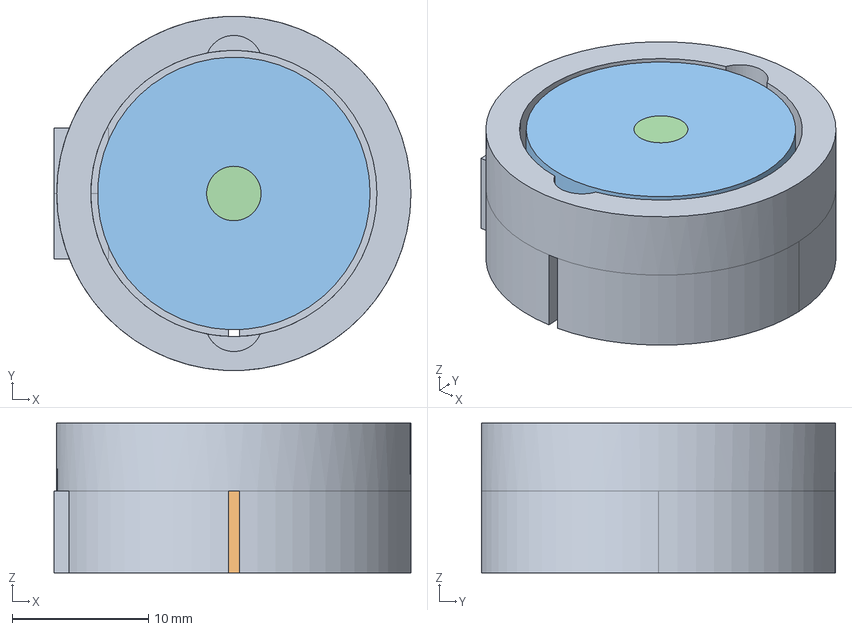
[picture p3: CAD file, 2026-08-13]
mechanical/freecad/macros/SR-MEC-001_RevE.FCStd
26.2 x 26.0 x 11.0 mm
SR-MEC-001 Rev.E - magneticky unasec
REFERENCE - osmihran 16.70 mm
REFERENCE - pevny uchyt (kontrolni Ø20 mm)
Magnet 1 - Ø4x2 mm

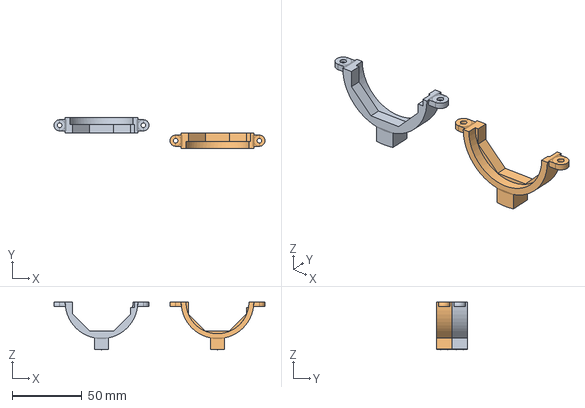
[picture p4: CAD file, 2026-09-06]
mechanical/freecad/magneticky_unasec/SR-MEC-001_RevE14.FCStd
151.0 x 22.0 x 34.0 mm
SR-MEC-001 - Polovina A (Zapuštěná hlava)
SR-MEC-001 - Polovina B (Rovná plocha matice)

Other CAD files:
mechanical/freecad/magneticky_unasec/SR-MEC-001_RevE14.stl

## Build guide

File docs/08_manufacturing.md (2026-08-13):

# SmartRoll – Manufacturing

This document will contain approved manufacturing parameters, 3D-printing orientation, material, tolerances, post-processing, assembly instructions and inspection criteria.

## Status

Material, print process and final manufacturing tolerances are currently `OPEN`.

No open manufacturing parameter shall be treated as a final production requirement.

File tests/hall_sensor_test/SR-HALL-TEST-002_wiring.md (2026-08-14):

# SR-HALL-TEST-002 — Arduino Nano + 2× A3144 Wiring

## Power

The complete test assembly is powered from the Arduino Nano USB connection.

**No external power supply is required.**

Use the Arduino Nano **5V** pin as the Hall sensor supply and a Nano **GND** pin as the common ground.

## Pin assignment

| Function | Arduino Nano | Hall A (A3144) | Hall B (A3144) |
|---|---|---|---|
| Supply | 5V | VCC | VCC |
| Ground | GND | GND | GND |
| Hall A output | D2 | OUT | — |
| Hall B output | D3 | — | OUT |

> **Important:** verify the actual pin numbering/pinout of the A3144 package received before applying power. Do not rely only on the physical orientation of a drawing.

## Hall A — exact connections

```text
Arduino Nano 5V
     |
     +---------------------> A3144 VCC
     |
    10 kΩ
     |
     +---------------------> A3144 OUT
     |
     +---------------------> Arduino D2

Arduino Nano GND ----------> A3144 GND
```

### Hall A bypass capacitor

Connect **100 nF ceramic** directly between the Hall A supply pins:

```text
A3144 VCC ----+---- 100 nF ----+---- A3144 GND
             |                 |
             +5 V              GND
```

Place this capacitor physically as close to the Hall sensor as practical.

## Hall B — exact connections

```text
Arduino Nano 5V
     |
     +---------------------> A3144 VCC
     |
    10 kΩ
     |
     +---------------------> A3144 OUT
     |
     +---------------------> Arduino D3

Arduino Nano GND ----------> A3144 GND
```

### Hall B bypass capacitor

Connect **100 nF ceramic** directly between the Hall B supply pins:

```text
A3144 VCC ----+---- 100 nF ----+---- A3144 GND
             |                 |
             +5 V              GND
```

Place this capacitor physically as close to the Hall sensor as practical.

## Complete connection overview

```text
                         ARDUINO NANO
                    +-------------------+
 USB 5 V ---------->| USB               |
                    |                   |
       +5 V --------| 5V                |
       GND ---------| GND               |
                    |                   |
       Hall A OUT --| D2                |
       Hall B OUT --| D3                |
                    +-------------------+
          |  |  |       |       |
          |  |  |       |       |
          |  |  +-------+-------+------------------- GND
          |  |          |       |
          |  |         10k     10k
          |  |          |       |
          |  +-------- Hall A  Hall B
          |             OUT     OUT
          |
          +----------------------------------------- +5 V

Hall A:
  VCC -> +5 V
  GND -> GND
  OUT -> D2
  10 kΩ from OUT to +5 V
  100 nF from VCC to GND

Hall B:
  VCC -> +5 V
  GND -> GND
  OUT -> D3
  10 kΩ from OUT to +5 V
  100 nF from VCC to GND
```

## Components

- Arduino Nano — 1×, powered by USB
- A3144 Hall sensor — 2×
- 10 kΩ resistor — 2×
- 100 nF ceramic capacitor — 2×
- USB cable — 1×
- test magnets
- jumper wires / breadboard as required

## Why the 10 kΩ resistors are here

The A3144 Hall switch has an open-collector output. The Arduino input therefore needs a pull-up to +5 V. Each Hall output receives its **own** 10 kΩ pull-up resistor.

Do not connect the 10 kΩ resistor from OUT to GND.

## Test inputs

- **D2 = Hall A**
- **D3 = Hall B**

These pins are intentionally chosen so the Arduino firmware can use interrupt-capable digital inputs for transition logging on a typical Nano/ATmega328P.

## Safety check before USB power

1. Confirm VCC-to-GND is not shorted on either Hall.
2. Confirm each 100 nF capacitor is between VCC and GND, not across OUT.
3. Confirm each 10 kΩ resistor is between +5 V and the corresponding OUT.
4. Confirm Hall A OUT goes only to D2.
5. Confirm Hall B OUT goes only to D3.
6. Confirm the exact A3144 package pinout from the received component documentation.
7. Only then connect USB power.

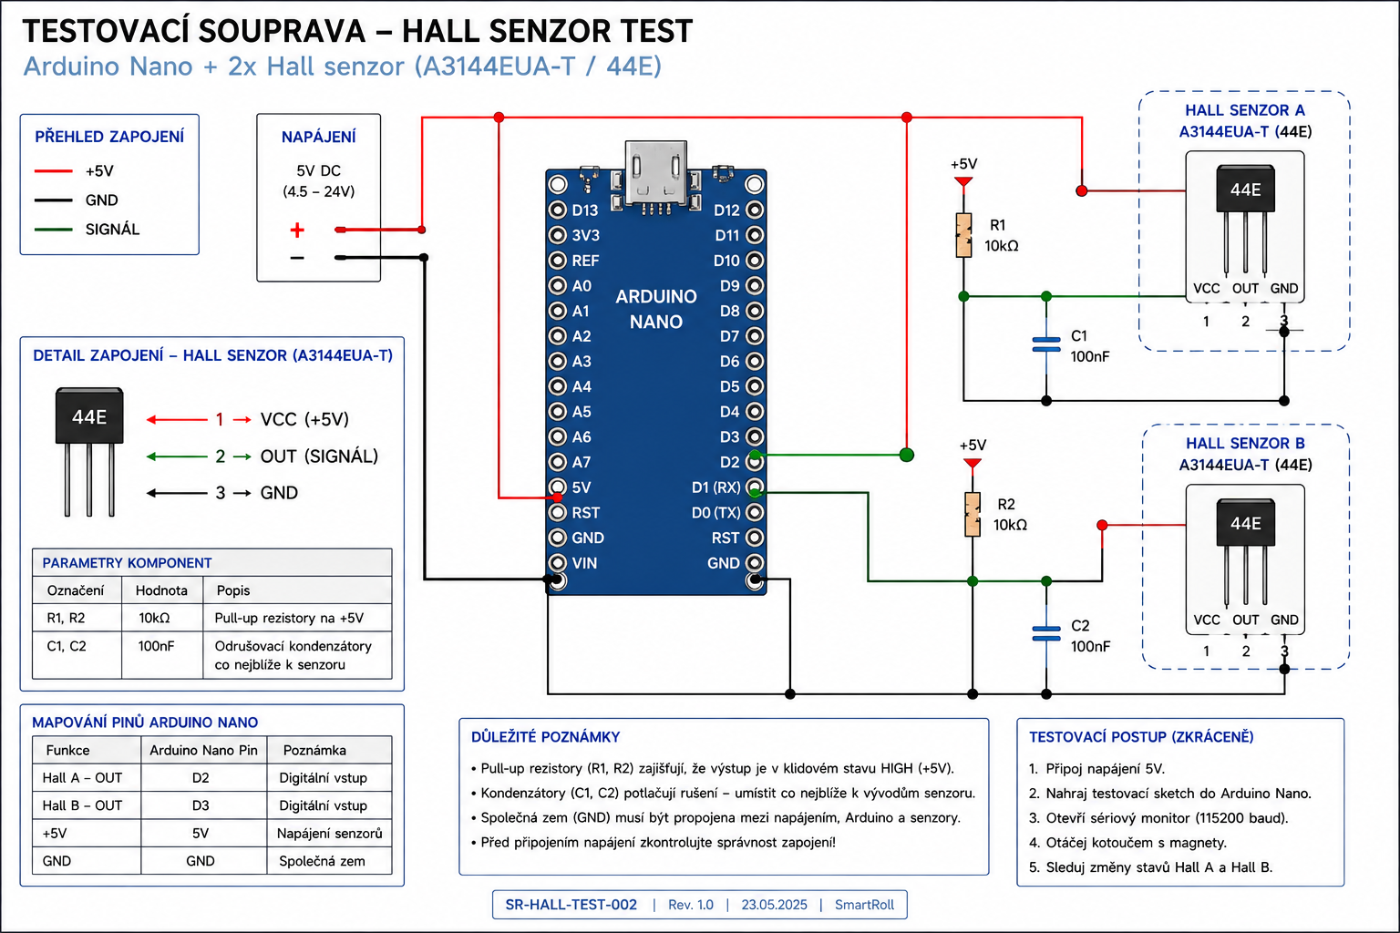
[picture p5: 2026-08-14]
tests/hall_sensor_test/Hall-Test-Wiring-Arduino.png

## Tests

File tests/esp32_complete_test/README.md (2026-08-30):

# SmartRoll – Test 6: Complete SmartRoll firmware

## Purpose

Test the first complete SmartRoll application firmware on one ESP32.

The firmware combines the subsystems already validated in Tests 2–5:

```text
ESP32
 ├── Hall A/B quadrature + direction
 ├── ERTE 433 MHz RF control
 ├── BH1750 light sensor
 ├── DS18B20 temperature sensor
 ├── Wi-Fi
 └── MQTT / Home Assistant
```

**PIR is not part of SmartRoll and is deliberately excluded.**

The first Test 6 build is intended for the laboratory fixture only. No live roller blind is required or affected.

## Home Assistant communication

The selected integration method is **MQTT**. The project already uses Mosquitto, while the ESP32 retains direct control of the proven ERTE RF protocol and Hall interrupt decoder.

Home Assistant MQTT discovery is used so the ESP32 can announce its device and entities automatically.

## Network topology

```text
                         Home network
                              │
                     ┌────────┴────────┐
                     │ Synology NAS     │
                     │ Home Assistant   │
                     │ Mosquitto        │
                     └────────┬────────┘
                              │
                         routed network
                              │
                     ┌────────┴────────┐
                     │ MikroTik IoT AP  │
                     │ dedicated Wi-Fi │
                     └────────┬────────┘
                              │
                         Wi-Fi / IoT
                              │
                           ESP32
```

Recommended firewall policy:

```text
IoT ESP32 ───── TCP/1883 ─────> MQTT broker on NAS
```

Other IoT-to-LAN access should remain blocked unless separately required.

## Hardware pins

| Function | ESP32 GPIO | Status |
|---|---:|---|
| Hall A | GPIO32 | validated |
| Hall B | GPIO33 | validated |
| ERTE RF DATA | GPIO25 | validated |
| BH1750 SDA | GPIO21 | validated |
| BH1750 SCL | GPIO22 | validated |
| DS18B20 DATA | GPIO27 | validated |

## Parallel operation architecture

One ESP32 runs one firmware. The functions are independent software modules serviced cooperatively:

```text
                    ESP32 firmware
                          │
       ┌──────────────────┼──────────────────┐
       │                  │                  │
   GPIO ISR            main loop          timers
       │                  │                  │
  Hall A/B          RF commands       sensors/MQTT
  immediate         Wi-Fi/MQTT        periodic jobs
  transitions       processing        status publish
```

The Hall ISR performs only the minimum transition decoding. It does not perform MQTT, Serial, sensor reads or RF transmission. Sensor reads and MQTT processing run outside the ISR.

This is essential because Hall edges must not be lost while the ESP32 is handling network traffic.

## Serial Monitor

Arduino IDE Serial Monitor: **115200 Bd**.

Commands:

```text
u = UP
s = STOP
d = DOWN
p = print complete status
r = reset relative Hall counters
h = help
```

Serial remains the local diagnostic/control interface during Test 6. Normal Home Assistant control uses MQTT.

## MQTT topics

Device ID:

```text
smartroll_01
```

Base topic:

```text
smartroll/smartroll_01
```

Command:

```text
smartroll/smartroll_01/cover/command
```

Payloads:

```text
UP
DOWN
STOP
```

Availability:

```text
smartroll/smartroll_01/availability
```

State:

```text
smartroll/smartroll_01/state
```

The state JSON contains Hall state/counts, direction, illuminance, temperature and Wi-Fi RSSI.

## Home Assistant entities

The intended first HA entities are:

- SmartRoll cover – UP/DOWN/STOP
- temperature
- illuminance
- Hall direction
- relative Hall position/count
- invalid Hall transition counter
- Wi-Fi RSSI
- firmware version

Absolute percentage position is intentionally **not implemented yet**. Hall-count-to-blind-position calibration remains open.

## Test 6 sequence

### 6A – local complete firmware

- boot ESP32
- verify Wi-Fi connection
- verify MQTT connection
- verify BH1750
- verify DS18B20
- verify Hall state
- verify RF subsystem
- verify Serial diagnostics

### 6B – Home Assistant discovery

- verify SmartRoll device appears in MQTT integration
- verify entities appear
- verify availability changes correctly

### 6C – Home Assistant RF control

- UP from HA
- STOP from HA
- DOWN from HA
- verify RF command reception on the laboratory receiver/fixture
- confirm Hall direction/count simultaneously

### 6D – sensors + movement

While the laboratory fixture is moving:

- Hall continues decoding
- temperature continues updating
- illuminance continues updating
- MQTT remains connected

### 6E – Wi-Fi/MQTT reconnect

- temporarily interrupt Wi-Fi
- restore Wi-Fi
- verify MQTT reconnect
- verify entities become available again
- verify Hall subsystem remains operational

### 6F – ESP32 reset

- reset ESP32 while stationary
- reset ESP32 during/after movement
- verify startup Hall state acquisition
- verify RF operation
- verify sensor operation
- verify MQTT/HA reconnection

### 6G – long combined operation

Operate the laboratory fixture through repeated UP/STOP/DOWN cycles while HA and all sensors remain active.

## Acceptance criteria

Test 6 passes when:

1. ESP32 boots reliably.
2. Wi-Fi connects to the dedicated IoT network.
3. MQTT connects to the broker.
4. Home Assistant discovers the SmartRoll device.
5. UP/STOP/DOWN can be commanded from HA.
6. ERTE RF remains reliable.
7. Hall direction remains correct during HA/RF control.
8. Invalid Hall transitions remain zero during normal operation.
9. BH1750 and DS18B20 provide valid measurements.
10. Wi-Fi/MQTT reconnect does not break Hall/RF operation.
11. ESP32 reset restores complete operation.

## Important limitation

This is the first complete application firmware. It is **not yet final production firmware**.

Still open after Test 6:

- exact Hall count → blind position calibration,
- final power-supply validation,
- OTA update policy,
- long-duration reliability,
- final enclosure/mechanical integration.

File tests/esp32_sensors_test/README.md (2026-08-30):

# SmartRoll – Test 5: ESP32 + Hall + RF + sensors

## Purpose

Add the two remaining local sensors to the already verified ESP32 Hall + ERTE RF subsystem:

- **BH1750** – ambient light level
- **DS18B20** – temperature

The aim is to verify that sensor reading does not disturb Hall quadrature decoding or ERTE RF control.

This test is intentionally still local. Wi-Fi, MQTT and Home Assistant are not included.

## Architecture

One ESP32 runs one firmware containing independent functions:

```text
ESP32
 ├── Hall A/B interrupt decoder
 ├── ERTE RF transmitter
 ├── BH1750 via I2C
 └── DS18B20 via 1-Wire
```

Hall transitions are handled by GPIO interrupts. Sensor reading and serial/RF handling remain in the main program. Sensor operations must not be placed inside the Hall ISR.

## Hardware

### Hall

Use the already approved Test 4 wiring:

```text
Hall A OUT -> GPIO32
Hall B OUT -> GPIO33
Hall A/B VCC -> 3.3 V
Hall A/B GND -> GND
10 kΩ pull-up from each OUT to 3.3 V
```

### ERTE RF

Use the already approved Test 4 wiring:

```text
RF DATA -> GPIO25
RF GND  -> ESP32 GND
RF VCC  -> module-rated supply
```

Do not change the proven RF timing or payload.

### BH1750

```text
BH1750 VCC -> ESP32 3.3 V
BH1750 GND -> ESP32 GND
BH1750 SDA -> ESP32 GPIO21
BH1750 SCL -> ESP32 GPIO22
```

The BH1750 is an I2C device. If the breakout already contains I2C pull-ups, no additional pull-ups should be added unless required by the particular board.

### DS18B20

```text
DS18B20 VDD  -> ESP32 3.3 V
DS18B20 GND  -> ESP32 GND
DS18B20 DATA -> ESP32 GPIO27
```

Add:

```text
4.7 kΩ between DATA and 3.3 V
```

Use the 3-wire powered configuration; do not use parasite power for this test.

## Required libraries

Arduino IDE:

- `BH1750`
- `OneWire`
- `DallasTemperature`
- `RF433send`

## Serial Monitor

Arduino IDE Serial Monitor:

```text
115200 Bd
```

Commands:

```text
u = UP
s = STOP
d = DOWN
p = print complete status
r = reset Hall counters / relative position
h = help
```

The firmware also prints sensor readings periodically:

```text
BH1750: 245.31 lx
DS18B20: 23.56 C
Hall: A=1 B=1 Position=... CW=... CCW=... Invalid=0
RF: idle
```

## Test sequence

### Test 5A – sensors alone

1. Start ESP32.
2. Confirm BH1750 gives a plausible lux value.
3. Confirm DS18B20 gives a plausible temperature.
4. Leave the system running for several minutes.
5. Confirm no resets or sensor communication errors.

### Test 5B – sensors + Hall

1. Start the firmware.
2. Observe sensor readings.
3. Rotate the Hall test fixture in both directions.
4. Verify CW/CCW decoding.
5. Verify `Invalid=0`.
6. Confirm sensor readings continue while Hall transitions occur.

### Test 5C – sensors + RF

1. Send UP.
2. Send STOP.
3. Send DOWN.
4. Confirm the roller responds correctly.
5. Confirm BH1750 and DS18B20 continue reporting.

### Test 5D – all functions simultaneously

Run several complete cycles:

```text
UP -> STOP -> DOWN -> STOP
```

while monitoring:

- Hall direction
- Hall transition count
- invalid transitions
- RF command result
- BH1750 reading
- DS18B20 reading

### Test 5E – reset

1. Run the complete system.
2. Reset ESP32.
3. Confirm both sensors initialize again.
4. Confirm Hall state initializes correctly.
5. Send UP/STOP/DOWN.
6. Confirm RF remains operational.

## Pass criteria

Test 5 passes when:

- BH1750 provides stable plausible readings.
- DS18B20 provides stable plausible readings.
- Hall CW/CCW remains correct.
- `Invalid=0` during normal movement.
- RF UP/STOP/DOWN remains reliable.
- Sensor reading does not cause missed Hall transitions.
- Sensor reading does not corrupt RF transmission.
- ESP32 reset restores all four subsystems.

## Important

This test validates sensor coexistence only. It does **not** yet validate Wi-Fi, MQTT or Home Assistant.

Those are added in Test 6.

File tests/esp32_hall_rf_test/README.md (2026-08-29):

# SmartRoll – Test 4: ESP32 + Hall + ERTE RF

## Purpose

Test the two already verified subsystems running together on one ESP32:

```text
                 ┌── Hall A/B quadrature decoder
ESP32 ───────────┤
                 └── ERTE 433 MHz RF transmitter
```

The purpose is to verify that Hall movement tracking and RF control can operate concurrently without interfering with each other.

## Why several functions can run on one ESP32

The ESP32 is not running several programs simultaneously. It runs one firmware, but that firmware is divided into independent tasks that are serviced repeatedly by the processor.

For SmartRoll the important principle is:

- Hall A/B is handled by GPIO interrupts. A Hall edge can therefore be captured immediately even while the main program is doing other work.
- RF commands are generated only when requested and the RF transmission occupies the processor for a short, defined period.
- The main `loop()` remains non-blocking for normal status handling, command processing and diagnostics.
- The two subsystems share the same ESP32 but use different GPIOs and independent software state.

For the final SmartRoll firmware we will keep time-consuming operations out of the Hall interrupt handler. The ISR will only capture the Hall transition and update the minimal decoder state.

This test therefore establishes the architecture needed for the final unit before adding BH1750, DS18B20 and Wi-Fi/MQTT.

## Hardware

### Hall subsystem

```text
Hall A VCC  -> ESP32 3V3
Hall A GND  -> ESP32 GND
Hall A OUT  -> ESP32 GPIO32

Hall B VCC  -> ESP32 3V3
Hall B GND  -> ESP32 GND
Hall B OUT  -> ESP32 GPIO33

3V3 -> 10 kΩ -> Hall A OUT / GPIO32
3V3 -> 10 kΩ -> Hall B OUT / GPIO33
```

### RF subsystem

```text
433 MHz transmitter VCC  -> 5 V
433 MHz transmitter GND  -> ESP32 GND
433 MHz transmitter DATA -> ESP32 GPIO25
```

The transmitter is the tested three-pin VCC/DATA/GND module documented in Test 3.

## Serial Monitor interface

Arduino IDE Serial Monitor is the test control panel and diagnostic display.

Baud rate:

```text
115200
```

### Commands

```text
u = UP
s = STOP
 d = DOWN
r = reset software counters/relative position
p = print current status
h = print help
```

The space before `d` in this document is only typographical; the actual command is the single character `d`.

### Example

```text
> u
RF: UP sent

> p
Hall: A=1 B=1
Position: 0
CW: 0  CCW: 0  Invalid: 0
RF: idle

> d
RF: DOWN sent
```

While the blind is moving, Hall transitions are reported by the diagnostic output. The user can therefore see both activities in the same Serial Monitor session.

## What we are testing

The important point is that the user does **not** manually switch between separate Hall and RF programs. One firmware provides both functions through the Serial Monitor.

Example test:

```text
1. Send 'u' in Serial Monitor.
2. Blind starts moving UP.
3. Hall A/B transitions are captured automatically.
4. Position/direction counters change automatically.
5. Send 's'.
6. RF STOP is transmitted.
7. Hall activity stops when the blind stops.
8. Send 'd'.
9. Blind moves DOWN and Hall direction changes accordingly.
```

The Hall decoder must continue working regardless of whether an RF command was just sent.

## Test sequence

### A – stationary baseline

1. Start/reset ESP32.
2. Do not move the fixture/blind.
3. Observe Hall state for at least 30 seconds.
4. Verify no spontaneous transitions.

Expected:

```text
invalid = 0
position unchanged
```

### B – RF UP + Hall tracking

1. Send `u`.
2. Observe the blind moving UP.
3. Verify Hall transitions.
4. Verify decoded direction remains consistent.
5. Send `s`.
6. Verify the blind stops.

### C – RF DOWN + Hall tracking

1. Send `d`.
2. Verify movement DOWN.
3. Verify Hall direction changes to the opposite direction.
4. Send `s`.

### D – repeated cycles

Perform several:

```text
UP -> STOP -> DOWN -> STOP
```

Observe Hall counters after every cycle.

### E – RF commands while Hall is active

While the blind is moving and Hall transitions are being generated, issue STOP and then the opposite movement command. Verify that no Hall decoder corruption occurs.

### F – ESP32 reset

1. Move the blind.
2. Reset ESP32.
3. Verify boot and Hall initial state.
4. Send RF commands again.
5. Verify Hall decoding and RF operation remain functional.

## Pass criteria

Test 4 passes when:

- RF UP works while Hall decoding is active.
- RF STOP works while Hall decoding is active.
- RF DOWN works while Hall decoding is active.
- Hall CW/CCW direction remains correct during RF operation.
- `invalid=0` during normal test movement.
- No false direction changes are caused by RF transmission.
- Repeated UP/STOP/DOWN cycles remain stable.
- ESP32 reset does not prevent either subsystem from operating again.

## Important limitation

This test does not yet validate BH1750, DS18B20, Wi-Fi, MQTT or Home Assistant. Those are intentionally added later so that any failure remains attributable to the Hall/RF combination.

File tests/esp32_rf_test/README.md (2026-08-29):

# SmartRoll – Test 3: ESP32 + ERTE RF

## Purpose

Verify that the ERTE FT45E RF protocol previously implemented and proven in ControlRoll can be generated directly by the ESP32.

This test intentionally isolates RF. Hall A/B, BH1750, DS18B20 and Wi-Fi/Home Assistant are not used.

The original ControlRoll implementation used the `RF433send` library with a TRIBIT encoder and the same timing configuration used here. The library supports ESP32, so Test 3 preserves the proven protocol instead of re-implementing it.

## Confirmed RF transmitter

The test uses the exact three-pin 433 MHz ASK/OOK transmitter module referenced by Components101:

- **VCC**
- **DATA**
- **GND**

Reference: https://components101.com/modules/433-mhz-rf-transmitter-module

### Logical wiring

```text
RF transmitter VCC  -> 5 V supply
RF transmitter GND  -> ESP32 GND
RF transmitter DATA -> ESP32 GPIO25
```

The transmitter is powered from its specified supply. The DATA control line is driven by the ESP32 at 3.3 V logic. No 5 V signal is connected back to an ESP32 GPIO.

For development the ESP32 and transmitter are powered from the low-voltage USB/5 V side. The 230 V SmartRoll power supply is not part of Test 3.

## Confirmed ERTE payloads

For roller 1:

```text
UP:   33 63 13 79 08
STOP: 33 63 13 79 2A
DOWN: 33 63 13 79 19
```

These are the same payloads used by ControlRoll and are frozen for this test.

## Test firmware

`esp32_erte_rf_test.ino`

Serial Monitor: **115200 Bd**

Commands:

```text
01C = UP
01B = STOP
01A = DOWN
```

## Test performed

The physical Test 3 setup was connected to an ERTE roller blind and tested directly from the ESP32.

Observed result:

- `01A` / DOWN: roller blind moved fully down.
- `01B` / STOP: roller blind stopped.
- `01C` / UP: roller blind moved fully up.

The blind accepted the ESP32-generated RF transmission and all three basic functions were demonstrated.

Evidence:

`evidence/ESP32-test-RF.txt`

## Current result

**PASS – basic ESP32 RF compatibility confirmed.**

This confirms that the ESP32 can directly generate the already proven ERTE RF protocol with the selected 433 MHz transmitter module.

## Remaining reliability checks

The basic functional test is passed. Before final SmartRoll integration, the following should still be recorded if desired:

- repeated UP/STOP/DOWN transmissions,
- operation after ESP32 reset,
- rapid command sequence.

These are reliability/robustness checks; they do not change the already proven RF payload or timing parameters.

## Next stage

After the RF basic test, integrate the two already verified subsystems:

```text
ESP32
 ├── Hall A/B quadrature
 └── ERTE RF
```

Only after this combined test is stable should BH1750, DS18B20 and Wi-Fi/Home Assistant integration be added.

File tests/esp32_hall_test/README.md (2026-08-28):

# SmartRoll – Test 2: ESP32 + Hall A/B

## Purpose

Verify that the quadrature Hall decoder already validated on the Arduino Nano works correctly on the ESP32.

This test deliberately contains **only ESP32 + Hall A + Hall B**. RF, Wi-Fi application communication, BH1750 and DS18B20 are not connected yet.

## Hardware

- ESP32-DevKitC 38-pin
- 2× Hall sensors from the approved Hall experiment
- 2× 10 kΩ pull-up resistors
- existing Merkur Hall test fixture
- jumper wires
- USB cable for ESP32 power/programming

## Logical wiring – definitive connection list

### Hall sensor A

```text
Hall A VCC  -> ESP32 3V3
Hall A GND  -> ESP32 GND
Hall A OUT  -> ESP32 GPIO32
```

Pull-up:

```text
ESP32 3V3 -> 10 kΩ resistor -> Hall A OUT / GPIO32
```

### Hall sensor B

```text
Hall B VCC  -> ESP32 3V3
Hall B GND  -> ESP32 GND
Hall B OUT  -> ESP32 GPIO33
```

Pull-up:

```text
ESP32 3V3 -> 10 kΩ resistor -> Hall B OUT / GPIO33
```

### Complete logical schema

```text
ESP32 3V3
   ├──────────────> Hall A VCC
   ├──────────────> Hall B VCC
   ├──[10 kΩ]─────> Hall A OUT / GPIO32
   └──[10 kΩ]─────> Hall B OUT / GPIO33

ESP32 GND
   ├──────────────> Hall A GND
   └──────────────> Hall B GND

Hall A OUT ─────────> ESP32 GPIO32
Hall B OUT ─────────> ESP32 GPIO33
```

### Important

- ESP32 GPIOs are **3.3 V logic**.
- Hall VCC is connected to **ESP32 3V3**, not 5 V.
- Do **not** connect a 5 V Hall output directly to GPIO32 or GPIO33.
- The 10 kΩ pull-ups are used when the selected Hall output is open-collector/open-drain.
- No RC capacitor is added in this first ESP32 test. We first verify the raw digital transitions.

## Mechanical arrangement

Use the already validated Hall test fixture:

- two magnets 180° apart,
- Hall A and Hall B directly beside each other,
- approximately 5 mm air gap.

The Hall sensors must remain mechanically fixed during the test.

## Expected quadrature sequences

Clockwise:

```text
11 -> 10 -> 00 -> 01 -> 11
```

Counter-clockwise:

```text
11 -> 01 -> 00 -> 10 -> 11
```

## Test procedure

1. Connect only ESP32 and Hall A/B.
2. Upload `esp32_hall_test.ino`.
3. Open Serial Monitor at **115200 baud**.
4. Leave the fixture stationary and verify that the state remains stable.
5. Rotate 5 complete turns clockwise.
6. Rotate 5 complete turns counter-clockwise.
7. Repeat at higher speed.
8. Press RESET on the ESP32 and repeat both directions.
9. Record the complete serial output in `evidence/`.

## Acceptance criteria

The test passes when:

- CW is always decoded as CW,
- CCW is always decoded as CCW,
- no false direction changes occur,
- `invalid = 0`,
- rapid rotation does not create invalid transitions,
- reset does not break decoding,
- the relative position returns to its starting value after equal clockwise and counter-clockwise movement.

Absolute roller position is **not** evaluated in this test.

## Next test

After Test 2 passes, the next step is **ESP32 + frozen ERTE RF protocol**, followed by the critical combined **Hall + RF + Wi-Fi concurrency test**.

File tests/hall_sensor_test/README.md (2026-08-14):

# SmartRoll – Hall Sensor Test

## Purpose

This test is performed before finalizing the Hall sensor and magnet selection for the SmartRoll roller-blind position/direction system.

The test must verify the real magnetic/electrical behavior rather than relying only on catalog values.

## Test objectives

1. Verify that the candidate Hall sensor switches reliably with the candidate magnet.
2. Measure practical switching and release distance.
3. Verify that the magnet orientation is suitable for the intended radial carrier mounting.
4. Verify that two Hall sensors can produce a usable phase relationship.
5. Determine whether the intended two-magnet arrangement (180° apart) can produce reliable A/B quadrature transitions.
6. Determine a practical Hall-to-magnet air gap.
7. Identify whether the candidate Hall/magnet combination should be APPROVED or REJECTED.

## Current test status

**PLANNED – NOT YET TESTED**

## Important design rule

The current Hall sensor and magnet entries in the project BOM are candidates only. No component is approved for production until this test is completed.

## Test setup

- Arduino: existing test Arduino supplied by the project owner
- Hall sensors: 2 × candidate Hall sensor
- Magnets: candidate neodymium magnets, initially targeting approximately 4 × 2 mm
- Breadboard / prototype wiring
- 5 V supply suitable for the Arduino and Hall sensor
- Multimeter recommended
- 3D-printed adjustable test fixture
- PC with serial monitor/logger

## Test principle

A rotating test carrier or manually rotated magnet arrangement is used to reproduce the magnetic geometry expected in the final carrier.

The two Hall channels are called **A** and **B**.

The Arduino records both digital states and the sequence of transitions.

Expected quadrature behavior is:

Direction 1:

`00 → 01 → 11 → 10 → 00`

Direction 2:

`00 → 10 → 11 → 01 → 00`

The actual assignment of Direction 1/2 to WIND/UNWIND is intentionally left open until the final installation test.

## Test stages

### T1 – Single Hall / single magnet

- Verify wiring and logic level.
- Determine which magnet pole causes activation.
- Measure approximate switching distance.
- Measure release distance.
- Repeat at several air gaps.

### T2 – Radial magnet orientation

Mount the magnet in the same radial orientation intended for the final carrier.

Verify reliable switching while the magnet passes the Hall sensor tangentially.

### T3 – Two Hall sensors

Install Hall A and Hall B in an adjustable fixture.

Start with a candidate angular separation corresponding to the two-magnet geometry and adjust experimentally.

Record the Hall A/B waveform and transition order.

### T4 – Two magnets / 180° arrangement

Use two identical magnets positioned 180° apart on the test carrier.

Rotate the carrier slowly through at least two complete revolutions in each direction.

Record:

- Hall A state,
- Hall B state,
- transition sequence,
- number of transitions per revolution,
- missed transitions,
- false transitions.

### T5 – Speed test

Repeat the test at increasing rotation speeds until the expected maximum practical shaft speed is exceeded or the sensor system begins to miss transitions.

### T6 – Direction verification

Confirm that clockwise and counter-clockwise rotation produce opposite valid quadrature sequences.

## Acceptance criteria

The candidate system is acceptable only if:

- both Hall channels switch repeatably,
- no significant false switching occurs while stationary,
- the intended radial magnet orientation works,
- the A/B sequence is unambiguous in both directions,
- no transitions are systematically missed at the expected shaft speed,
- the selected air gap is mechanically achievable in the final carrier,
- the magnet does not interfere mechanically with the carrier or stationary parts.

## Measurements to record

| Parameter | Result | Status |
|---|---:|---|
| Hall sensor part number | TBD | OPEN |
| Magnet part number | TBD | OPEN |
| Magnet dimensions | TBD | OPEN |
| Magnet pole orientation | TBD | OPEN |
| Switching distance | TBD | OPEN |
| Release distance | TBD | OPEN |
| Practical air gap | TBD | OPEN |
| Hall A/B angular spacing | TBD | OPEN |
| Transitions / revolution | TBD | OPEN |
| Maximum tested speed | TBD | OPEN |
| False transitions | TBD | OPEN |
| Missed transitions | TBD | OPEN |
| Final result | TBD | OPEN |

## Evidence

Test photographs, oscilloscope/serial captures and measured values should be stored in this directory or its `evidence/` subdirectory.

Do not overwrite original measurement evidence.

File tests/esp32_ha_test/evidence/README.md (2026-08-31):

# Test 6B.1 Evidence

Place test evidence in this directory.

Recommended:

- `esp32_ha_testB1_serial.txt` – ESP32 Serial Monitor output
- `mqtt_explorer_B1.png` – MQTT Explorer showing SmartRoll topics/payloads
- `home_assistant_B1.png` – Home Assistant showing the temporary MQTT entities

The test is complete when the PASS criteria in `../TEST6B1_MQTT_TO_HA.md` are satisfied.

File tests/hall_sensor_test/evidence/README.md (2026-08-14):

# Hall Sensor Test Evidence

Store original test evidence here:

- photographs,
- serial monitor captures,
- oscilloscope screenshots,
- measurement notes,
- test videos.

Do not overwrite original evidence. Use descriptive filenames with a test stage prefix, for example:

`T1_01_single_magnet_switching.jpg`
`T3_02_AB_sequence.txt`
`T4_01_two_magnets_video.mp4`

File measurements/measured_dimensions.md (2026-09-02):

# SmartRoll – Measured Dimensions

This file is the consolidated measurement register for the mechanical SmartRoll design.

## Status legend

- **CONFIRMED** – explicitly measured/confirmed by the user or supported by the measurement record.
- **DECIDED** – design decision, not a physical measurement.
- **REFERENCE** – useful reference value from an existing CAD revision; not automatically a physical measurement.
- **OPEN** – must still be measured or confirmed.
- **SUPERSEDED** – historical value replaced by a newer confirmed value.

## 1. Roller blind / installation

| Parameter | Value | Status | Evidence / note |
|---|---:|---|---|
| Application | External roller blind | CONFIRMED | Project specification |
| Motor | ERTE ET 45E | CONFIRMED | Project specification |
| Roller shaft | Octagonal | CONFIRMED | Photos + previous measurements |
| Shaft nominal description | 8 × 17 mm | REFERENCE | `images/roller_blind/rozmery.txt`; this is not the same definition as AF |
| Shaft across flats | 16.70 mm | CONFIRMED | Explicitly measured/confirmed during design |
| Slat-side total width | 5 + 7.0 + 5 mm = 17.0 mm | CONFIRMED | Explicitly corrected during design |
| Slat feature width | 6.70 mm | CONFIRMED | Explicitly corrected during design; previous 7 mm is obsolete |
| Cabinet depth | 160 mm | CONFIRMED | `rozmery.txt` |
| Cabinet height | 160 mm | CONFIRMED | `rozmery.txt` |
| Wound blind distance from wall | approx. 30 mm | CONFIRMED | `rozmery.txt` and design discussion |
| Unwound available space | approx. 35 mm | CONFIRMED | Direct design measurement |
| Effective wound clearance | approx. 30 mm | CONFIRMED | Critical design condition |
| Rotating section starts from right | approx. 24 mm | CONFIRMED / APPROXIMATE | Direct measurement/discussion |
| Programming button | Must remain accessible | DECIDED | Right-side stationary motor part |

## 2. Carrier geometry – approved design decisions

| Parameter | Value | Status | Note |
|---|---:|---|---|
| Carrier architecture | Two-piece | DECIDED | Two halves installed independently |
| Clamping width | 6.00 mm | DECIDED | Available shaft attachment zone |
| Clamping profile | Octagonal | DECIDED | Must engage shaft positively |
| Magnetic collar width | 5.00 mm | DECIDED | Total carrier width 11 mm |
| Magnetic internal clearance | Circular | DECIDED | Must rotate around stationary part |
| Magnet count | 2 | DECIDED | Opposed pair |
| Magnet angular spacing | 180° | DECIDED | Opposed pair |
| Magnet orientation | Radial | DECIDED | Inserted from outer circumference |
| Magnet nominal size | 4 × 2 mm | DECIDED | Final magnet orientation/dimensions to be verified against purchased parts |
| M3 connections | 2 | DECIDED | Used to clamp two carrier halves |
| Slat clearance orientation | 90° from joining arrangement | DECIDED | Chosen to avoid putting the slat feature at a split |

## 3. Historical CAD-only values – do not treat as confirmed

The following values appear in previous FreeCAD revisions and are therefore useful for reconstructing design history, but they are **not physical measurements unless independently confirmed**:

| Parameter | Historical value | Revision(s) | Status |
|---|---:|---|---|
| Carrier outer diameter | Ø26.00 mm | E1/E2/E5 | REFERENCE |
| Magnetic circular clearance | Ø21.00 mm | E1/E2/E5 | REFERENCE |
| Shaft clearance added in CAD | 0.20 mm | E1/E2/E5 | REFERENCE / design tolerance |
| M3 through-hole | Ø3.30 mm | E2/E5 | REFERENCE |
| M3 head recess | 1.20–2.30 mm depending revision | E2/E5 | SUPERSEDED / OPEN |
| Nut AF | 5.50 mm | E2/E5 | REFERENCE |
| Magnet pocket | Ø4.20 mm × approx. 2.15 mm | E1/E2/E5 | REFERENCE |
| Clamp slot width | 0.80 mm | E1/E2/E5 | REFERENCE |

## 4. Important correction history

### Shaft side dimension

A previous CAD iteration used **7.00 mm** for one shaft side. This is superseded.

The confirmed geometry is:

`5.0 + 6.7 + 5.0 = 16.7 mm`

The 6.70 mm slat feature must therefore not be silently replaced by 7.00 mm in future macros.

### Magnetic collar internal profile

Early concepts incorrectly retained octagonal internal geometry through the magnetic collar. The approved concept is:

- 0–6 mm: octagonal shaft-clamping bore;
- 6–11 mm: circular internal clearance.

The reason is that the magnetic collar rotates around the stationary motor-holder geometry.

### Carrier installation

The original single-slit ring concept was rejected as potentially impractical to open sufficiently in tough ABS.

The approved architecture is two separate halves joined by two M3 screws.

## 5. Open measurements required before production macro

The following must be measured or confirmed before a production-ready FreeCAD model is released:

1. Exact external dimensions of the stationary black motor-holder.
2. Exact diameter/profile of the part around which the magnetic collar must rotate.
3. Exact axial position and usable 6 mm clamping zone relative to the right-side end.
4. Exact programming-button position and required access envelope.
5. Exact slat feature depth and cross-section.
6. Exact minimum clearance in the fully wound condition at the carrier location.
7. Exact magnet dimensions of the selected physical magnets.
8. Exact Hall sensor position relative to the magnet path.
9. Required 3D-printing clearance for the shaft fit.

## 6. Evidence files

Primary measurement evidence currently stored in:

`images/roller_blind/`

Relevant files include:

- `Detail_zamereni_1.jpeg` … `Detail_zamereni_6.jpeg`
- `pravy-rozvinuto-detail.jpeg`
- `pravy-navinuto-detail.jpeg`
- `pravy-bocni pohled-navinuto.jpeg`
- `pravy-rozvinuto-situace.jpeg`
- `levy-rozvinuto.jpeg`
- `rozmery.txt`

Operational reference videos:

- `navijeni-levy-video.MOV`
- `navijeni-pravy-video.MOV`

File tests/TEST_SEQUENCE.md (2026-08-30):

# SmartRoll – Complete Test Sequence

This document is the master validation sequence for the SmartRoll project. Tests are performed incrementally so that each subsystem is proven independently before subsystems are combined.

## Principle

**Do not move to the next integration stage until the preceding stage has passed.**

The purpose is to isolate faults and avoid changing several variables at once.

---

## Test 1 – Hall sensor hardware and geometry

**Location:** `tests/hall_sensor_test/`

**Status: PASS – Hall hardware and final mechanical arrangement accepted.**

---

## Test 2 – ESP32 + Hall A/B quadrature

**Location:** `tests/esp32_hall_test/`

**Status: PASS – ESP32 Hall subsystem accepted.**

---

## Test 3 – ESP32 + ERTE RF

**Location:** `tests/esp32_rf_test/`

**Status: PASS – ESP32 RF subsystem accepted.**

---

# Test 4 – ESP32 + Hall + RF

**Location:** `tests/esp32_hall_rf_test/`

### Completed subtests

- **4A – stationary baseline: PASS**
- **4B – RF UP + Hall tracking: PASS**
- **4C – RF DOWN + Hall tracking: PASS**
- **4D – repeated UP/STOP/DOWN cycles: PASS**
- **4E – RF commands during Hall activity: PASS**
- **4F – ESP32 reset: PASS**

### Result

**PASS – Test 4 completed successfully.**

---

# Test 5 – ESP32 + Hall + RF + sensors

**Location:** `tests/esp32_sensors_test/`

### Completed subtests

- **5A – sensors alone: PASS**
- **5B – sensors + Hall: PASS**
- **5C – sensors + RF: PASS**
- **5D – all functions simultaneously: PASS**
- **5E – ESP32 reset: PASS**

### Result

**PASS – Test 5 completed successfully.**

---

# Test 6 – Complete SmartRoll firmware + Home Assistant

**Location:** `tests/esp32_complete_test/`

### Objective

Integrate all validated functions in one ESP32 application and connect it to Home Assistant through the existing Mosquitto MQTT broker.

```text
                    ESP32 SmartRoll
                          │
       ┌──────────────────┼──────────────────┐
       │                  │                  │
   Hall A/B             ERTE RF          Sensors
       │                  │             ┌───┴────┐
       │                  │             │BH1750  │
       │                  │             │DS18B20 │
       │                  │             │PIR     │
       └──────────────────┼─────────────┴────────┘
                          │
                       Wi-Fi
                          │
                      IoT network
                          │
                       MQTT
                          │
                  Home Assistant
```

### Firmware

`tests/esp32_complete_test/smartroll_test6.ino`

### Home Assistant integration

`tests/esp32_complete_test/HA_MQTT.md`

### Test stages

- **6A – complete local firmware:** NOT TESTED
- **6B – Home Assistant MQTT discovery:** NOT TESTED
- **6C – Home Assistant RF control:** NOT TESTED
- **6D – sensors + movement:** NOT TESTED
- **6E – Wi-Fi/MQTT reconnect:** NOT TESTED
- **6F – ESP32 reset:** NOT TESTED
- **6G – long combined operation:** NOT TESTED

### Important

The Test 6 firmware keeps the proven RF payload/timing and Hall transition decoder. The new elements are the application layer, Wi-Fi, MQTT and Home Assistant discovery.

Absolute blind position is intentionally not implemented yet because Hall-count-to-blind-position calibration remains OPEN.

**Status: IN PROGRESS – firmware prepared, physical/HA testing not yet completed.**

---

# Test 7 – Power supply and complete hardware

### Objective

Validate the final SmartRoll hardware, including the selected 230 V AC → low-voltage power supply/step-down solution.

**Status: PLANNED**

---

# Test 8 – Long-duration / final reliability test

### Objective

Operate a complete SmartRoll unit for an extended period and verify that no cumulative software or hardware fault develops.

**Status: PLANNED**

---

# Test status overview

| Test | System | Status |
|---|---|---|
| 1 | Hall hardware + geometry | PASS |
| 2 | ESP32 + Hall A/B | PASS |
| 3 | ESP32 + ERTE RF | PASS |
| 4 | ESP32 + Hall + RF | **PASS** |
| 5 | Hall + RF + BH1750 + DS18B20 | **PASS** |
| 6 | Complete SmartRoll + Home Assistant | **IN PROGRESS** |
| 7 | Final hardware + 230 V supply | PLANNED |
| 8 | Long-duration reliability | PLANNED |

## Important design decisions carried through all tests

### Position after power failure

SmartRoll does **not** require absolute roller position recovery after a power failure. The motor's own upper and lower electronic limits remain the authoritative physical limits. SmartRoll tracks relative movement/direction and can resynchronize during a complete opening or closing cycle.

### Platform

The development tests use ESP32 because the final SmartRoll controller will also use ESP32. The Arduino Nano was used for the initial Hall/RF proof-of-concept only.

### RF protocol

The ERTE RF payload and timing validated in ControlRoll and Test 3 are frozen. Future integration tests must not modify the RF protocol unless a separate investigation is explicitly opened.

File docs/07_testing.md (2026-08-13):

# SmartRoll – Testing

This document will contain the verification plan for mechanical fit, rotation, Hall signal sequence, direction detection, calibration, endurance and final system behavior.

## Status

The detailed test protocol is currently `OPEN`.

Every confirmed mechanical revision should eventually have a corresponding verification record.

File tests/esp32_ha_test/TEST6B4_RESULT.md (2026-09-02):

# TEST 6B.4 – HA MQTT Cover

**Výsledek: PASS**  
**Datum:** 2026-09-02

## Cíl testu

Ověřit finální ovládání rolety v Home Assistant prostřednictvím MQTT Cover s použitím již ověřených příkazů:

- `UP`
- `STOP`
- `DOWN`

Použit byl již ověřený MQTT command topic:

`smartroll/smartroll_01/cover/command`

## Výsledek

Test 6B.4 proběhl úspěšně.

MQTT Cover v Home Assistant funguje spolehlivě a správně ovládá ESP32/RF část systému.

## Stav

Tímto je laboratorní část **6B** uzavřena jako úspěšná.

Ověřené funkce zahrnují:

- ESP32 → Wi-Fi → MQTT → Home Assistant
- HA → MQTT → ESP32
- MQTT Cover UP / STOP / DOWN
- RF ovládání ERTE
- Hall A/B
- směr otáčení
- relativní počítání polohy
- teplotu
- osvětlení

## Co nebylo součástí testu

Test 6B.4 neřešil absolutní kalibraci polohy rolety:

- skutečnou polohu CLOSED / OPEN
- počet impulsů mezi skutečnými koncovými polohami
- převod impulsů na 0–100 %
- automatické nastavení polohy v procentech
- finální kalibraci na skutečné roletě

Tyto funkce budou řešeny až v etapě **6C**, po dokončení mechanické konstrukce a přípravě kompletního finálního zařízení.

## Závěr

**TEST 6B.4 = PASS**

MQTT Cover v Home Assistant je funkční a spolehlivý. Další vývoj se nyní přesouvá z laboratorního ověřování elektroniky a HA na **mechanickou konstrukci SmartRoll**. 

Při mechanickém vývoji se nemění již ověřené funkční části elektroniky a firmware.

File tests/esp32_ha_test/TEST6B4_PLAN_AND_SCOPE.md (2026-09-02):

# SmartRoll – Test 6B.4 – MQTT Cover v Home Assistant

**Status: PLANNED / PARTIAL – Cover entity to be prepared**

## Purpose

Test 6B.4 completes the laboratory Home Assistant integration only to the level that is meaningful on the current Merkur mechanical test fixture.

The goal is to prepare a Home Assistant MQTT Cover entity using the already validated SmartRoll MQTT command interface. The laboratory fixture is **not** used for calibration of the real roller-blind position.

## Current laboratory setup

The SmartRoll electronics and firmware are being tested on a mechanical test fixture assembled from Merkur components. This fixture is suitable for verification of communication, RF commands, Hall sensing, direction detection and relative pulse counting, but it is not the final mechanical construction of the roller blind controller.

## Scope of 6B.4

The following functionality may be prepared and tested:

- Home Assistant MQTT Cover entity.
- Open command: `UP`.
- Close command: `DOWN`.
- Stop command: `STOP`.
- Existing MQTT command topic:

```text
smartroll/smartroll_01/cover/command
```

- Verification that the Cover uses the already validated ESP32 firmware and RF path.
- Preservation of the already tested Hall A/B, direction, relative position, temperature and light functions.
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

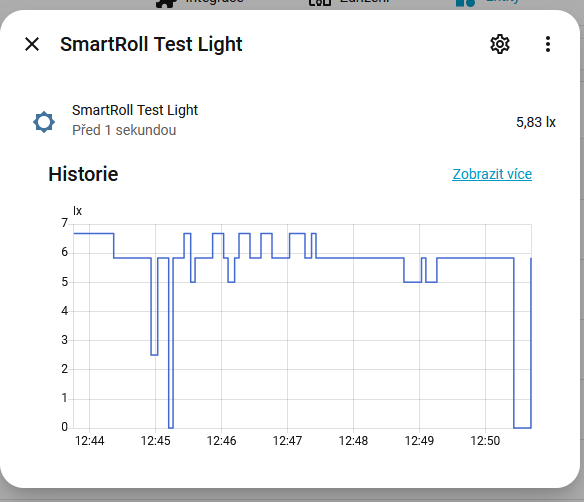
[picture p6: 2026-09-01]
tests/esp32_complete_test/evidence/HA-Light-test.png

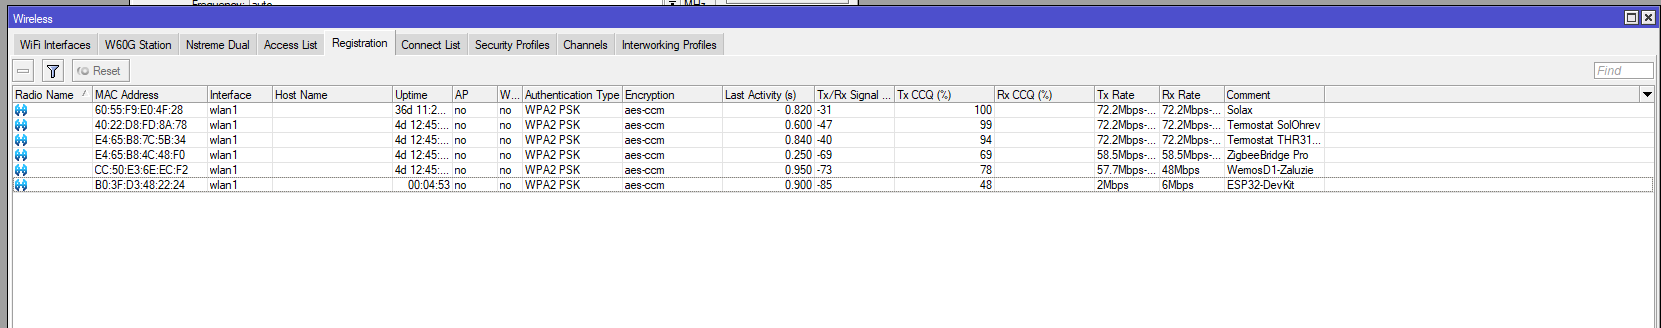
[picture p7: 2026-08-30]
tests/esp32_complete_test/evidence/Snímek obrazovky 2026-08-30 235140.png

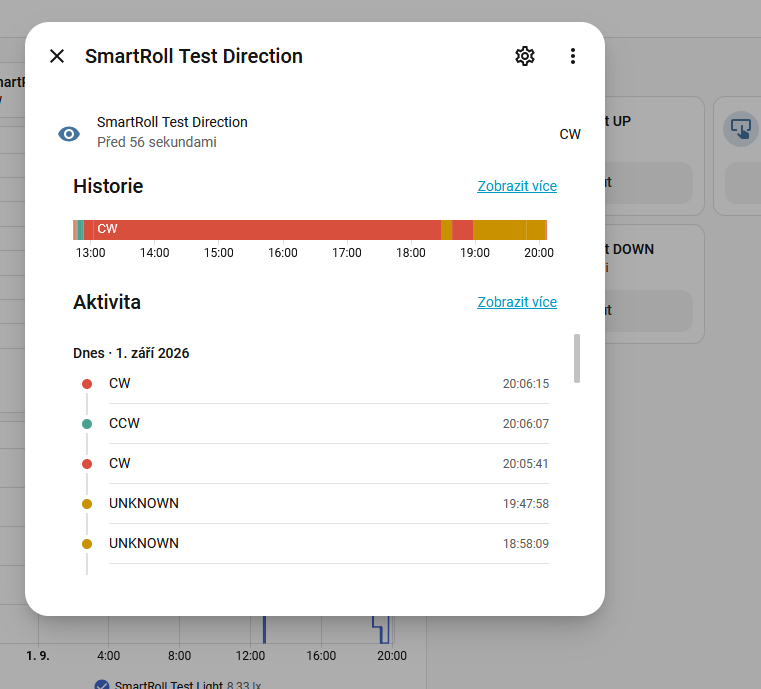
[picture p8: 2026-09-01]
tests/esp32_ha_test/evidence/HA-MQTT-RF-direction.png

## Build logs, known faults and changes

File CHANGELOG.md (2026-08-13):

# SmartRoll Change Log

## 2026-08-13 – Initial documentation baseline

### Added

- Initial `SPECIFICATION.md`.
- Project documentation structure defined in `README.md`.
- Established parameter status system: `CONFIRMED`, `DECIDED`, `ASSUMED`, `OPEN`, `SUPERSEDED`.
- Established rule that confirmed/decided parameters must not be changed silently.
- Established SR-MEC-001 mechanical revision tracking.

### SR-MEC-001 Rev.F baseline

Confirmed:

- external roller-blind application,
- ERTE ET 45E tubular motor,
- octagonal shaft,
- 16.70 mm across flats,
- 5 + 6.7 + 5 mm geometry on the slat side,
- approximately 35 mm available space with blind unrolled,
- approximately 30 mm effective space with blind wound,
- rotating section begins approximately 24 mm from the right,
- programming button must remain accessible.

Decided:

- two-piece carrier,
- two M3 connections,
- 6 mm octagonal clamping section,
- slat clearance 90° from the joining arrangement,
- circular clearance in the magnetic section,
- two radial magnets,
- magnets 180° apart,
- nominal magnets 4 × 2 mm,
- magnets inserted radially from the outside,
- carrier installed as two separate halves rather than opening a complete ring,
- approximately 30 mm wound-blind condition is the critical clearance state,
- production FreeCAD macros must expose open dimensions instead of silently guessing them.

Open:

- exact slat geometry,
- exact stationary-holder geometry,
- final magnetic-section dimensions,
- final outer diameter,
- final M3 boss geometry,
- final magnet-pocket dimensions,
- final printing tolerances,
- final material and printing parameters,
- final CAD coordinate convention,
- detailed Hall sensor geometry.

## 2026-08-14 – Mechanical consolidation

### Added

- Created `measurements/measured_dimensions.md` as the consolidated measurement register.
- Consolidated the physical measurement note `images/roller_blind/rozmery.txt` with the previously confirmed dimensions.
- Documented the distinction between the nominal `8 × 20 mm` shaft note and the confirmed `16.70 mm across flats` dimension.
- Consolidated the FreeCAD development history from Rev.A through Rev.E5.
- Documented which CAD values are historical references rather than physical measurements.

### Superseded / clarified

- The previous 7.00 mm shaft-side value is superseded by the confirmed 6.70 mm slat feature within the 5 + 6.7 + 5 mm geometry.
- Octagonal internal geometry through the magnetic collar is superseded by the circular rotating clearance concept.
- The single-piece elastic-opening carrier concept is superseded by the approved two-piece carrier architecture.
- Axial magnet insertion is superseded by radial insertion from the outer circumference.

### Current mechanical status

The historical Rev.E5 macro is the latest CAD implementation currently stored, but it is **not declared the production revision**. The production candidate must first incorporate the approved two-piece architecture and the remaining OPEN physical dimensions.

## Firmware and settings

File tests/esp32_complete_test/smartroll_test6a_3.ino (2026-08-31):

/*
  SmartRoll - TEST 6A.3
  Complete integration test: ESP32 + Hall + ERTE RF + BH1750 + DS18B20 + Wi-Fi + MQTT

  RF implementation is copied from validated Test 5 / Test 3 and MUST NOT be changed.
  PIR is NOT part of SmartRoll.

  Serial Monitor: 115200 Bd
  Commands: u=UP, d=DOWN, s=STOP, p=STATUS, r=reset Hall, h=HELP

  Do NOT store real Wi-Fi or MQTT credentials in GitHub.
*/

#include <Arduino.h>
#include <WiFi.h>
#include <PubSubClient.h>
#include <Wire.h>
#include <BH1750.h>
#include <OneWire.h>
#include <DallasTemperature.h>
#include <RF433send.h>

const char* WIFI_SSID     = "YOUR_IOT_SSID";
const char* WIFI_PASSWORD = "YOUR_WIFI_PASSWORD";
const char* MQTT_HOST     = "YOUR_MQTT_BROKER_IP";
const uint16_t MQTT_PORT  = 1883;
const char* MQTT_USER     = "YOUR_MQTT_USER";
const char* MQTT_PASSWORD = "YOUR_MQTT_PASSWORD";

const char* DEVICE_ID = "smartroll_01";
const char* FW_VERSION = "0.6.3-test6A3";

const uint8_t HALL_A_PIN = 32;
const uint8_t HALL_B_PIN = 33;
const uint8_t RF_PIN = 25;
const uint8_t I2C_SDA_PIN = 21;
const uint8_t I2C_SCL_PIN = 22;
const uint8_t DS18B20_PIN = 27;

const byte data_up[]   = {0x33, 0x63, 0x13, 0x79, 0x08};
const byte data_stop[] = {0x33, 0x63, 0x13, 0x79, 0x2A};
const byte data_down[] = {0x33, 0x63, 0x13, 0x79, 0x19};

// IMPORTANT: RfSend is abstract. Use the exact builder configuration proven in Test 5.
RfSend* tx_erte = nullptr;
WiFiClient wifiClient;
PubSubClient mqtt(wifiClient);
BH1750 lightMeter;
OneWire oneWire(DS18B20_PIN);
DallasTemperature tempSensor(&oneWire);

const int8_t transitionTable[16] = {
   0, -1, +1,  2,
  +1,  0,  2, -1,
  -1,  2,  0, +1,
   2, +1, -1,  0
};

volatile uint8_t previousState = 0;
volatile int32_t position = 0;
volatile uint32_t cwCount = 0;
volatile uint32_t ccwCount = 0;
volatile uint32_t invalidCount = 0;
volatile uint32_t transitionCount = 0;
volatile int8_t lastDirection = 0;

enum MotionState { STOPPED, UP, DOWN };
MotionState motionState = STOPPED;

float lux = NAN;
float temperature = NAN;
bool bh1750Ok = false;
bool ds18b20Ok = false;

uint32_t lastSensorRead = 0;
uint32_t lastStatusPrint = 0;
uint32_t lastWifiAttempt = 0;
uint32_t lastMqttAttempt = 0;
const uint32_t SENSOR_INTERVAL_MS = 2000;
const uint32_t STATUS_INTERVAL_MS = 2000;
const uint32_t WIFI_RETRY_MS = 5000;
const uint32_t MQTT_RETRY_MS = 5000;

String baseTopic;
String stateTopic;
String commandTopic;
String availabilityTopic;

void IRAM_ATTR hallISR() {
  uint8_t currentState = (digitalRead(HALL_A_PIN) << 1) | digitalRead(HALL_B_PIN);
  if (currentState == previousState) return;
  uint8_t index = (previousState << 2) | currentState;
  int8_t movement = transitionTable[index];
  transitionCount++;
  if (movement == 1) {
    position++; cwCount++; lastDirection = 1;
  } else if (movement == -1) {
    position--; ccwCount++; lastDirection = -1;
  } else if (movement == 2) {
    invalidCount++;
  }
  previousState = currentState;
}

void sendRF(const char* name, const char* code, const byte* data, size_t len, MotionState newState) {
  Serial.printf("TX %s %s : ", code, name);
  for (size_t i = 0; i < len; i++) {
    if (data[i] < 0x10) Serial.print('0');
    Serial.print(data[i], HEX);
    if (i + 1 < len) Serial.print(' ');
  }
  Serial.println();
  byte repetitions = tx_erte->send(len, data);
  motionState = newState;
  Serial.printf("RF send repetitions: %u\n", repetitions);
}

void readSensors() {
  if (millis() - lastSensorRead < SENSOR_INTERVAL_MS) return;
  lastSensorRead = millis();
  if (bh1750Ok) lux = lightMeter.readLightLevel();
  if (ds18b20Ok) {
    tempSensor.requestTemperatures();
    temperature = tempSensor.getTempCByIndex(0);
  }
}

void printStatus() {
  int32_t p; uint32_t cw, ccw, inv, tr; uint8_t state; int8_t dir;
  noInterrupts();
  p=position; cw=cwCount; ccw=ccwCount; inv=invalidCount; tr=transitionCount;
  state=previousState; dir=lastDirection;
  interrupts();
  Serial.println("--------------------------------------------");
  Serial.printf("Wi-Fi: %s", WiFi.status()==WL_CONNECTED ? "CONNECTED" : "OFFLINE");
  if (WiFi.status()==WL_CONNECTED) Serial.printf("  IP=%s RSSI=%d dBm", WiFi.localIP().toString().c_str(), WiFi.RSSI());
  Serial.println();
  Serial.printf("MQTT: %s\n", mqtt.connected() ? "CONNECTED" : "OFFLINE");
  Serial.printf("Hall: A=%d B=%d position=%ld CW=%lu CCW=%lu transitions=%lu invalid=%lu\n",
    (state>>1)&1, state&1, (long)p, (unsigned long)cw, (unsigned long)ccw, (unsigned long)tr, (unsigned long)inv);
  Serial.printf("Direction: %s\n", dir>0 ? "CW" : dir<0 ? "CCW" : "UNKNOWN");
  Serial.printf("BH1750: %.2f lx [%s]\n", lux, bh1750Ok ? "OK" : "ERROR");
  Serial.printf("DS18B20: %.2f C [%s]\n", temperature, ds18b20Ok ? "OK" : "ERROR");
  Serial.printf("Motion command state: %s\n", motionState==UP ? "UP" : motionState==DOWN ? "DOWN" : "STOPPED");
}

void mqttCallback(char* topic, byte* payload, unsigned int length) {
  String msg;
  for (unsigned int i=0; i<length; i++) msg += (char)payload[i];
  msg.trim(); msg.toUpperCase();
  if (msg=="UP") sendRF("UP", "01C", data_up, sizeof(data_up), UP);
  else if (msg=="DOWN") sendRF("DOWN", "01A", data_down, sizeof(data_down), DOWN);
  else if (msg=="STOP") sendRF("STOP", "01B", data_stop, sizeof(data_stop), STOPPED);
}

void connectWiFi() {
  Serial.println("Wi-Fi: connection attempt");
  WiFi.mode(WIFI_STA);
  WiFi.begin(WIFI_SSID, WIFI_PASSWORD);
}

void ensureWiFi() {
  if (WiFi.status()==WL_CONNECTED) return;
  if (millis()-lastWifiAttempt < WIFI_RETRY_MS) return;
  lastWifiAttempt=millis();
  connectWiFi();
}

void ensureMQTT() {
  if (WiFi.status()!=WL_CONNECTED || mqtt.connected()) return;
  if (millis()-lastMqttAttempt < MQTT_RETRY_MS) return;
  lastMqttAttempt=millis();
  Serial.println("MQTT: connection attempt");
  String clientId=String(DEVICE_ID)+"_"+String((uint32_t)ESP.getEfuseMac(),HEX);
  bool ok;
  if (strlen(MQTT_USER)==0) ok=mqtt.connect(clientId.c_str(),availabilityTopic.c_str(),0,true,"offline");
  else ok=mqtt.connect(clientId.c_str(),MQTT_USER,MQTT_PASSWORD,availabilityTopic.c_str(),0,true,"offline");
  if (ok) {
    Serial.println("MQTT: CONNECTED");
    mqtt.publish(availabilityTopic.c_str(),"online",true);
    mqtt.subscribe(commandTopic.c_str());
  } else Serial.printf("MQTT: FAILED state=%d\n",mqtt.state());
}

void publishState() {
  if (!mqtt.connected()) return;
  int32_t p; uint32_t cw,ccw,inv,tr; uint8_t state; int8_t dir;
  noInterrupts(); p=position; cw=cwCount; ccw=ccwCount; inv=invalidCount; tr=transitionCount; state=previousState; dir=lastDirection; interrupts();
  String payload="{";
  payload += "\"hall_a\":"+String((state>>1)&1)+",";
  payload += "\"hall_b\":"+String(state&1)+",";
  payload += "\"position\":"+String(p)+",";
  payload += "\"cw\":"+String(cw)+",";
  payload += "\"ccw\":"+String(ccw)+",";
  payload += "\"transitions\":"+String(tr)+",";
  payload += "\"invalid\":"+String(inv)+",";
  payload += "\"direction\":\""+String(dir>0?"CW":dir<0?"CCW":"UNKNOWN")+"\",";
  payload += "\"lux\":"+String(lux,2)+",";
  payload += "\"temperature\":"+String(temperature,2)+",";
  payload += "\"rssi\":"+String(WiFi.RSSI());
  payload += "}";
  mqtt.publish(stateTopic.c_str(),payload.c_str(),true);
}

void printHelp() { Serial.println("Commands: u=UP d=DOWN s=STOP p=STATUS r=reset Hall h=HELP"); }

void handleSerial() {
  while (Serial.available()) {
    char c=Serial.read();
    if(c=='u'||c=='U') sendRF("UP","01C",data_up,sizeof(data_up),UP);
    else if(c=='d'||c=='D') sendRF("DOWN","01A",data_down,sizeof(data_down),DOWN);
    else if(c=='s'||c=='S') sendRF("STOP","01B",data_stop,sizeof(data_stop),STOPPED);
    else if(c=='p'||c=='P') printStatus();
    else if(c=='r'||c=='R') {
      noInterrupts(); position=0; cwCount=0; ccwCount=0; invalidCount=0; transitionCount=0; lastDirection=0; interrupts();
      Serial.println("Hall counters reset");
    }
    else if(c=='h'||c=='H') printHelp();
  }
}

void setup() {
  Serial.begin(115200); delay(1000);
  Serial.println();
  Serial.println("============================================");
  Serial.println("SmartRoll TEST 6A.3");
  Serial.println("ESP32 + Hall + ERTE RF + BH1750 + DS18B20 + Wi-Fi + MQTT");
  Serial.println("============================================");

  pinMode(HALL_A_PIN,INPUT_PULLUP);
  pinMode(HALL_B_PIN,INPUT_PULLUP);
  previousState=(digitalRead(HALL_A_PIN)<<1)|digitalRead(HALL_B_PIN);
  attachInterrupt(digitalPinToInterrupt(HALL_A_PIN),hallISR,CHANGE);
  attachInterrupt(digitalPinToInterrupt(HALL_B_PIN),hallISR,CHANGE);

  // EXACT proven RF builder from Test 5.
  tx_erte=rfsend_builder(
    RfSendEncoding::TRIBIT,
    RF_PIN,
    RFSEND_DEFAULT_CONVENTION,
    4,
    nullptr,
    9712,
    5048,
    1472,
    0,
    362,
    722,
    0,
    0,
    704,
    9360,
    39
  );
  Serial.println("RF: ready");

  Wire.begin(I2C_SDA_PIN,I2C_SCL_PIN);
  bh1750Ok=lightMeter.begin(BH1750::CONTINUOUS_HIGH_RES_MODE);
  Serial.printf("BH1750: %s\n",bh1750Ok?"OK":"ERROR");

  tempSensor.begin();
  ds18b20Ok=tempSensor.getDeviceCount()>0;
  Serial.printf("DS18B20: %s (%u device(s))\n",ds18b20Ok?"OK":"ERROR",tempSensor.getDeviceCount());

  // Wi-Fi sequence proven by Test 6A.2.
  WiFi.mode(WIFI_STA);
  WiFi.disconnect();
  delay(300);
  WiFi.begin(WIFI_SSID,WIFI_PASSWORD);
  Serial.println("Wi-Fi: connecting...");
  uint32_t start=millis();
  while(WiFi.status()!=WL_CONNECTED && millis()-start<15000) { delay(250); Serial.print('.'); }
  Serial.println();
  if(WiFi.status()==WL_CONNECTED) Serial.printf("Wi-Fi: CONNECTED IP=%s RSSI=%d dBm\n",WiFi.localIP().toString().c_str(),WiFi.RSSI());
  else Serial.printf("Wi-Fi: initial connection failed, status=%d\n",(int)WiFi.status());

  baseTopic=String("smartroll/")+DEVICE_ID;
  stateTopic=baseTopic+"/state";
  commandTopic=baseTopic+"/command";
  availabilityTopic=baseTopic+"/availability";
  mqtt.setServer(MQTT_HOST,MQTT_PORT);
  mqtt.setCallback(mqttCallback);
  printHelp();
  printStatus();
}

void loop() {
  handleSerial();
  ensureWiFi();
  ensureMQTT();
  if(mqtt.connected()) mqtt.loop();
  readSensors();
  if(millis()-lastStatusPrint>=STATUS_INTERVAL_MS) {
    lastStatusPrint=millis();
    printStatus();
    publishState();
  }
  delay(2);
}

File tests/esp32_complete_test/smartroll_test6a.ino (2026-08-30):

/*
  SmartRoll - TEST 6A
  Local complete integration firmware

  Purpose of 6A:
    - integrate all validated hardware functions on one ESP32
    - verify Hall quadrature + ERTE RF + BH1750 + DS18B20
    - verify Wi-Fi connection to the dedicated IoT network
    - verify basic MQTT connection/telemetry
    - keep control available from Arduino IDE Serial Monitor

  Home Assistant MQTT Discovery is deliberately NOT used in 6A.
  HA integration is the next stage (6B), after local operation is stable.

  PIR is NOT part of SmartRoll.

  Validated pin assignment:
    Hall A       GPIO32
    Hall B       GPIO33
    ERTE RF DATA GPIO25
    BH1750 SDA   GPIO21
    BH1750 SCL   GPIO22
    DS18B20 DATA GPIO27

  DS18B20 pull-up:
    4.7 kOhm preferred; 10 kOhm is acceptable for the laboratory test.

  Serial Monitor: 115200 Bd

  Serial commands:
    u = UP
    s = STOP
    d = DOWN
    p = status
    r = reset Hall counters / relative position
    h = help

  IMPORTANT:
    Never put real Wi-Fi or MQTT credentials into GitHub.
    Replace the placeholders locally before flashing.
*/

#include <Arduino.h>
#include <WiFi.h>
#include <PubSubClient.h>
#include <Wire.h>
#include <BH1750.h>
#include <OneWire.h>
#include <DallasTemperature.h>
#include <RF433send.h>

// ================= CONFIGURATION =================
const char* WIFI_SSID     = "YOUR_IOT_SSID";
const char* WIFI_PASSWORD = "YOUR_WIFI_PASSWORD";
const char* MQTT_HOST     = "YOUR_MQTT_BROKER_IP";
const uint16_t MQTT_PORT  = 1883;
const char* MQTT_USER     = "YOUR_MQTT_USER";
const char* MQTT_PASSWORD = "YOUR_MQTT_PASSWORD";

const char* DEVICE_ID   = "smartroll_01";
const char* DEVICE_NAME = "SmartRoll";
const char* FW_VERSION  = "0.6.1-test6a";

// ================= PINOUT =================
const uint8_t HALL_A_PIN = 32;
const uint8_t HALL_B_PIN = 33;
const uint8_t RF_PIN = 25;
const uint8_t I2C_SDA_PIN = 21;
const uint8_t I2C_SCL_PIN = 22;
const uint8_t DS18B20_PIN = 27;

// ================= MQTT =================
String baseTopic;
String stateTopic;
String commandTopic;
String availabilityTopic;

WiFiClient wifiClient;
PubSubClient mqtt(wifiClient);
BH1750 lightMeter;
OneWire oneWire(DS18B20_PIN);
DallasTemperature tempSensor(&oneWire);
RfSend *tx_erte = nullptr;

// ================= ERTE RF =================
// This is the tested Test 3 RF protocol and timing. Do not alter here.
const byte data_1nahoru[] = {0x33, 0x63, 0x13, 0x79, 0x08};
const byte data_1stop[]   = {0x33, 0x63, 0x13, 0x79, 0x2A};
const byte data_1dolu[]   = {0x33, 0x63, 0x13, 0x79, 0x19};

// ================= HALL QUADRATURE =================
// Index = previous_state * 4 + current_state
// +1 = CW, -1 = CCW, 2 = invalid transition, 0 = no movement
const int8_t transitionTable[16] = {
   0, -1, +1,  2,
  +1,  0,  2, -1,
  -1,  2,  0, +1,
   2, +1, -1,  0
};

volatile uint8_t previousState = 0;
volatile int32_t position = 0;
volatile uint32_t cwCount = 0;
volatile uint32_t ccwCount = 0;
volatile uint32_t invalidCount = 0;
volatile uint32_t transitionCount = 0;
volatile int8_t lastDirection = 0;  // +1 CW, -1 CCW, 0 unknown

// ================= APPLICATION STATE =================
enum MotionState {
  MOTION_STOPPED,
  MOTION_UP,
  MOTION_DOWN
};

MotionState motionState = MOTION_STOPPED;

float lastLux = NAN;
float lastTemperature = NAN;
bool bh1750Ok = false;
bool ds18b20Ok = false;

uint32_t lastSensorRead = 0;
uint32_t lastPublish = 0;
uint32_t lastStatus = 0;
uint32_t lastWifiAttempt = 0;
uint32_t lastMqttAttempt = 0;

const uint32_t SENSOR_INTERVAL_MS = 5000;
const uint32_t PUBLISH_INTERVAL_MS = 2000;
const uint32_t STATUS_INTERVAL_MS = 2000;
const uint32_t WIFI_RETRY_MS = 10000;
const uint32_t MQTT_RETRY_MS = 5000;

// ================= HALL ISR =================
void IRAM_ATTR hallISR()
{
  uint8_t currentState = (digitalRead(HALL_A_PIN) << 1) |
                         digitalRead(HALL_B_PIN);

  if (currentState == previousState) return;

  uint8_t index = (previousState << 2) | currentState;
  int8_t movement = transitionTable[index];
  transitionCount++;

  if (movement == 1) {
    position++;
    cwCount++;
    lastDirection = 1;
  }
  else if (movement == -1) {
    position--;
    ccwCount++;
    lastDirection = -1;
  }
  else if (movement == 2) {
    invalidCount++;
  }

  previousState = currentState;
}

// ================= RF =================
void sendRF(const char* name, const char* command,
            const byte* data, size_t length, MotionState newState)
{
  if (tx_erte == nullptr) {
    Serial.println("RF ERROR: transmitter not initialized");
    return;
  }

  Serial.print("TX ");
  Serial.print(command);
  Serial.print(" ");
  Serial.print(name);
  Serial.print(" : ");

  for (size_t i = 0; i < length; i++) {
    if (data[i] < 0x10) Serial.print('0');
    Serial.print(data[i], HEX);
    if (i + 1 < length) Serial.print(' ');
  }
  Serial.println();

  byte repetitions = tx_erte->send(length, data);
  motionState = newState;

  Serial.print("RF send repetitions: ");
  Serial.println(repetitions);
}

// ================= SENSORS =================
void readSensors()
{
  if (millis() - lastSensorRead < SENSOR_INTERVAL_MS) return;
  lastSensorRead = millis();

  if (bh1750Ok) {
    float lux = lightMeter.readLightLevel();
    if (lux >= 0) lastLux = lux;
  }

  if (ds18b20Ok) {
    tempSensor.requestTemperatures();
    float t = tempSensor.getTempCByIndex(0);
    if (t != DEVICE_DISCONNECTED_C && t > -100 && t < 125) {
      lastTemperature = t;
    }
  }
}

// ================= STATUS SNAPSHOT =================
void getHallSnapshot(int32_t &p, uint32_t &cw, uint32_t &ccw,
                     uint32_t &invalid, uint32_t &transitions,
                     uint8_t &state, int8_t &dir)
{
  noInterrupts();
  p = position;
  cw = cwCount;
  ccw = ccwCount;
  invalid = invalidCount;
  transitions = transitionCount;
  state = previousState;
  dir = lastDirection;
  interrupts();
}

const char* directionName(int8_t dir)
{
  if (dir > 0) return "CW";
  if (dir < 0) return "CCW";
  return "UNKNOWN";
}

const char* motionName()
{
  if (motionState == MOTION_UP) return "UP";
  if (motionState == MOTION_DOWN) return "DOWN";
  return "STOPPED";
}
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

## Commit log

2026-08-13 Add Hall sensor design baseline
2026-08-13 Create STL directory
2026-08-13 Create electronics schematics directory
2026-08-13 Create PCB directory
2026-08-13 Document external blinds and ERTE ET 45E motors
2026-08-13 Record external blind motor specification
2026-08-13 Expand Hall sensor direction detection specification
2026-08-14 Add project bill of materials and Dratek procurement baseline
2026-08-14 Create Hall sensor test project documentation
2026-08-14 Add Hall sensor test plan and procedure
2026-08-14 Add FreeCAD macro for adjustable Hall sensor test fixture
2026-08-14 Create Hall sensor test evidence directory
2026-08-14 Add simple visual overview of Hall sensor test fixture
2026-08-14 Add Arduino Nano Hall sensor test wiring schematic
2026-08-14 Add detailed Arduino Nano Hall sensor wiring schematic
2026-08-14 Add Arduino Nano Hall A/B test logger
2026-08-15 Add Hall sensor test measurement log template
2026-08-15 Add exact breadboard wiring layout for Arduino Nano Hall test
2026-08-15 Add visual breadboard wiring diagram for Hall sensor test
2026-08-18 Add single Hall sensor test firmware without floating Hall B input
2026-08-22 Document 90 and 45 degree Hall sensor tests
2026-08-22 Document 30 degree Hall sensor tests
2026-08-22 Define next Hall sensor test phase and measurement procedure
2026-08-22 Document Hall direction, restart behavior, ESP target
2026-08-22 Update Hall test results and ESP restart requirements
2026-08-22 Add Hall direction state-machine test firmware
2026-08-22 Fix direction state machine: establish direction only on unambiguous transitions
    [SR-HALL-TEST-004_DIRECTION.ino]
2026-08-23 Finalize Hall sensor specification after quadrature and reset validation
2026-08-23 Consolidate approved Hall quadrature specification; supersede obsolete angle tests
2026-08-24 Switch purchase baseline to ESP32 and preserve D1 as development fallback
2026-08-24 Adopt ESP32 as preferred SmartRoll controller and freeze RF migration baseline
2026-08-25 Update SmartRoll power supply to compact 230VAC to 5V AC-DC module
2026-08-25 Document compact isolated 230VAC to 5V SmartRoll power architecture
2026-08-26 Add ESP32 Hall test wiring documentation
2026-08-26 Add ESP32 Hall quadrature test firmware
2026-08-28 Simplify Test 2 wiring to logical point-to-point schema
2026-08-29 Document ESP32 Hall Test 1 and Test 2 results
2026-08-29 Add Test 3 ESP32 ERTE RF test documentation
2026-08-29 Add ESP32 ERTE RF test firmware
2026-08-29 Add detailed ESP32 ERTE RF test plan
2026-08-29 Add initial ESP32 RF test results template
2026-08-29 Record initial ESP32 ERTE RF functional test as PASS
2026-08-29 Add Test 4 plan: ESP32 Hall and RF concurrent operation
2026-08-29 Add Test 4 ESP32 Hall plus ERTE RF firmware
2026-08-29 Fix Test 4 RF implementation to match proven Test 3 RF433send API
    [esp32_hall_rf_test.ino]
2026-08-29 Record successful Test 4C Hall tracking during RF DOWN
2026-08-30 Mark Test 4 Hall plus RF integration as passed
2026-08-30 Add Test 5 ESP32 sensor integration firmware
2026-08-30 Mark Test 5 complete after successful sensor integration validation
2026-08-31 Add corrected SmartRoll Test 6A.3 firmware
    [smartroll_test6a_3.ino]
2026-08-31 Fix Test 6A.3 RF initialization using validated builder
    [smartroll_test6a_3.ino]
2026-09-01 Prepare Test 6B.3 Hall feedback with HA RF control
2026-09-02 Document scope of test 6B.4 and defer position calibration to phase 6C
2026-09-02 Add verified MQTT sensor configuration for test 6B.3
2026-09-03 Mechanical: create SR-MEC-001 Rev.E7 with measured 17 mm shaft and 7x2.5 mm svlak
2026-09-03 Mechanical: create SR-MEC-001 Rev.E8 with 7 mm octagon side
2026-09-03 Add SR-MEC-001 Rev.E9 with corrected 17 mm shaft and improved M3 nut access
